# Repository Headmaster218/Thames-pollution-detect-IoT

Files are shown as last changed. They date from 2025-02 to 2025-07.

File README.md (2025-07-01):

# Intelligent Waterborne Fecal Contamination Monitoring System

## AquaSense

This project presents a **low-cost, deployable, AI-integrated platform** for monitoring fecal contamination in natural waters. By using **inorganic water quality parameters** (e.g., DO, PH, turbidity, conductivity) as surrogate inputs, the system predicts **E. coli concentration** and collects physical water samples for future validation. It integrates **real-time sensing, wireless transmission, machine learning inference, data visualization, and automated water sampling**, forming a complete perception–prediction–collection loop.

## 🎥 Video preview

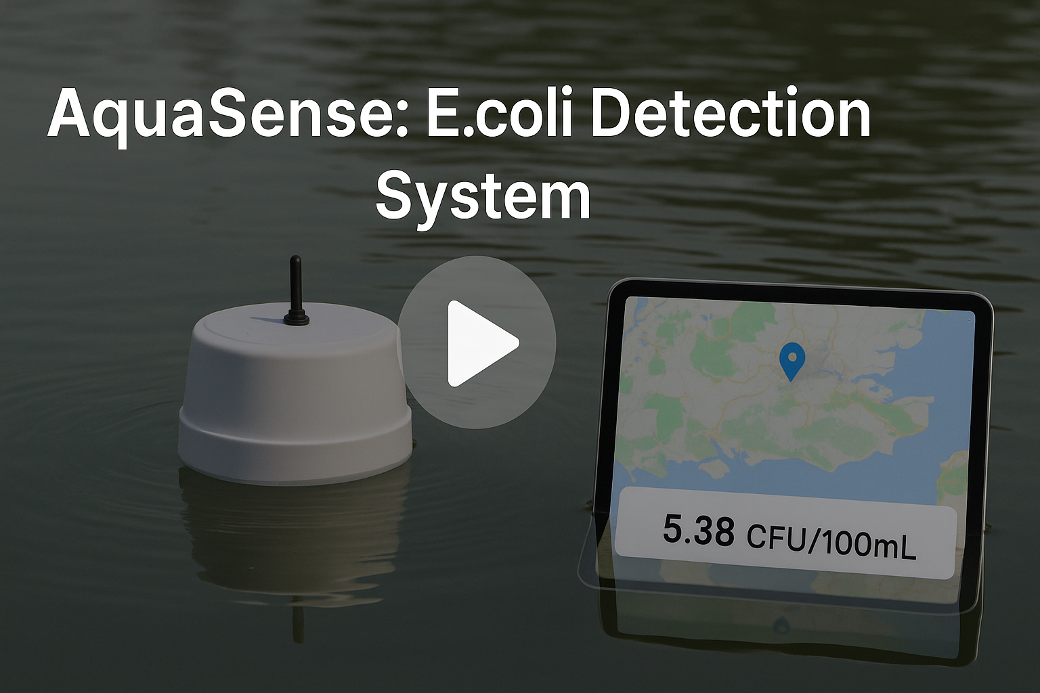
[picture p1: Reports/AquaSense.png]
Press Here~


---

## 📦 Project Summary

- **Title:** Integrated AI-driven Monitoring and Sampling System for Fecal Contamination in Urban Waters  
- **Core Idea:** Replace expensive, time-delayed E. coli testing methods with an inorganic-indicator-based prediction model
- **Application Scenario:** Urban rivers (e.g., Thames), lakes, and distributed low-resource field sites  

---

## 🧠 System Architecture

```
       +------------------+      LoRa        +-------------------+
       | Floating Buoy    |----------------->| LoRa Gateway      |
       | (Sensors + MCU)  |                  | (MQTT Broker)     |
       +--------+---------+                  +-------------------+
                |                                        |
                | LoRa                                   v MQTT
      +---------v---------+                       +---------------+
      | Autonomous Sampler|                       | Cloud Server  |
      | (RTC + Pump +     |<--------------------->| Data Storage  |
      |  Bottle Rotation) |                       +------+--------+
      +-------------------+                              |
                                                         v
                                 +-------------------------------+
                                 |   Web Dashboard & Mobile App  |
                                 |   (Real-time + Historical)    |
                                 +-------------------------------+
```
---

## 🧩 System Modules

### 1. 🧪 Sensor Unit (Floating Buoy)
- Turbidity, Dissolved Oxygen, PH, conductivity sensors
- Arduino-based circuit with solar power
- Periodic sampling + LoRa transmission

### 2. 🔄 Autonomous Sampling Unit 
- Peristaltic pump + rotating vial mechanism
- RTC-controlled periodic water collection
- Time-synced with sensor data via LoRa

### 3. 🌐 Server & Visualization
- LoRa gateway + MQTT + Python backend
- Database (SQLite)
- Web frontend with charts and map
- Mobile app with charts and map

### 4. 🧠 Machine Learning Module
- Trained neural network (FCN) on public water data (~23GB → 1MB preprocessed)
- Predicts log-scaled E. coli concentration
- RMSE ≈ 0.83 on test set
- Optional model variants: XGBoost, RF for comparison

---

## ⚙️ Deployment Features

- Fully solar-powered, suitable for field deployment
- Wireless transmission via LoRa (long range, low power)
- Real-time + historical data access
- Expandable to swarm systems or RL-based control

---

## 🚀 Key Contributions

- ✅ First attempt to estimate fecal contamination using only inorganic indicators  
- ✅ End-to-end system: sensing, prediction, visualization, sampling  
- ✅ Open-source, low-cost, and designed for global scalability  
- ✅ Modular and extensible: supports AI upgrades, edge deployment, or swarm coordination  

---

## 📌 Future Directions

- Integrate control strategies (e.g., RL-based adaptive sampling)  
- Train with real E. coli lab data using automated sampler  
- Edge deployment of ML model on MCU (TinyML)  
- Multi-node deployment and anomaly correlation  

---

## 📁 Folder Structure

```
Root/
├── 3D_Models/        # CAD models
├── Arduino_Code/     # Embedded firmware
├── Backend_code/     # Backend services, APIs
├── MLcode_Tommy_try/ # Experimental ML models by "Tommy"
├── ML_Main/          # Main ML pipeline: data, preprocess, training, model
├── Reports/          # Project documentation, research papers, final reports
└── Visualization/    # Frontend interfaces for data visualization and monitoring
    ├── APP/          # Mobile app interface "BlueGuardian"
    └── Web/          # Web dashboard 
```
---
## Author
Zhuohang Wu @
zhuohang2024@163.com

---

## 📬 Contact & Acknowledgements

For technical inquiries, collaboration requests, or feedback, feel free to contact:

**📌 Project Lead:**  
Zhuohang Wu (John) – zhuohang2024@163.com

**👥 Team Members:**  
Chenghao Xin, Xueyin Fan

**🧑‍🏫 Supervisors:**  
- Dr. Akin Delibasi – Department of Computer Science, UCL  
- Dr. Valerio Modugno – Department of Computer Science, UCL  
- Dr. Izzy Bishop – Department of Genetics, Evolution & Environment, UCL

---

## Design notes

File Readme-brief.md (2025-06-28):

# Project Summary: Low-Cost AI-Based Water Quality Monitoring System

This project aims to develop a **low-cost, deployable monitoring system** for detecting **fecal contamination** (specifically *E. coli*) in surface waters by using **inorganic water quality parameters** (e.g., turbidity, DO, Temperature, pH, conductivity) as surrogate indicators, combined with a machine learning model.

We have built a **fully integrated system** including real-time data collection, wireless transmission, AI-based prediction, web/mobile visualization, and a hardware module for **automatic water sampling**.

---

## ✅ Key Features

- **Inorganic surrogate-based prediction** of E. coli levels using a neural network  
- **Low-power floating buoy** with Arduino + sensors + solar power + LoRa transmission  
- **Web and mobile dashboard** showing real-time and historical data  
- **Autonomous sampling unit** that collects water samples at scheduled intervals for future lab testing  
- **Preliminary model** trained on public data (log-scale RMSE ≈ 0.83)

## 🎥 Video preview

Press Here~

---

## 📦 System Components

1. **Hardware:**  
   - turbidity, DO, Temperature, pH, conductivity sensors  
   - Arduino + LoRa + solar-powered buoy  
   - Peristaltic pump + rotating bottle module (sampler)

2. **Software:**  
   - Arduino + LoRa + MQTT server + database  
   - Web dashboard & mobile app with map and data queries

3. **AI Module:**  
   - Fully connected neural network  
   - Training data from UK water quality datasets  
   - Predicts log-transformed E. coli concentration

---

## 🎯 Project Goals

- Demonstrate feasibility of **non-biological real-time E. coli estimation**  
- Build a **complete monitoring + sampling platform** for environmental deployment  
- Prepare for future lab-based E. coli validation and AI model refinement

---

## 🔄 Current Status

- ✅ Core sensing and data transmission system completed  
- ✅ Dashboard and app functional  
- ✅ AI model trained with promising performance  
- 🛠️ Autonomous sampler hardware under construction (expected to complete soon)

---

## Author
Zhuohang Wu 
zhuohang2024@163.com

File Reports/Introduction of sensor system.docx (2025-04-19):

# Introduction of the sensor system

# final project

John Wu, MSc Internet of things, Computer science.

By the end of 20th of March 2024, human waste has been pumped into the Greater London area of the River Thames for a staggering 1,914 hours since the start of 2024 – equivalent to 79 days [1]! The human waste in it causes Waterborne Diseases, millions of pounds of financial loss and 116 thousand fish dying [2] in the river annually. However, detecting, tracing and predicting the source, distraction and trend of human waste is still a big problem.

Traditionally, people use organic solutions to detect human waste, such as microbial testing, DNA and RNA analysis [3], stable isotope analysis, etc. However, these solutions require expensive devices and a long duration. Based on these shortages, this project plans to develop a lower-cost and faster solution to detect human waste. This project plans to use multi-inorganic content including dissolved oxygen, ammonia nitrogen, conductivity and turbidity with an AI model to judge whether there is human waste in the water sample, what the concentration is and how long it has been in the water. In this solution, the cost is much lower than organic detection. Furthermore, real-time data will be accessible with the help of an AI model. Moreover, using this kind of sensor system, people can monitor the river for 7x24 hours rather than sample by humans and test in the lab.

However, there are still some potential challenges in this situation. For example, there will be a huge amount of data if the whole sensor system is complete. There will be hundreds of sensors, producing data constantly. How to process the data will be one of the most important challenges. Moreover, how to design a durable system is also important. As we all know, the sensors cannot be perfect all the time. Some of them may be broken or even produce wrong data. In this situation, how to make the system robust will be a main challenge.

In summary,

All in all, although with some challenges, this program is still meaningful to not only the citizens in London but also to the economic system in the whole world. This program is making effort on detect, trace and predict many kinds of human waste in the water system. By broaden this new method to the other rivers on this planet, it can provide us a solution to the pollution and make it a better world.

Reference

1. https://riveractionuk.com/thames-water-raw-sewage-dumped-in-the-river-thames-more-than-1900-hours-in-2024-so-far/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,Thames%20Water%3A%20raw%20sewage%20dumped%20in%20the%20River%20Thames%20more,hours%20in%202024%20so%20far&text=Thames%20Water%20has%20pumped%20human,2024%20–%20equivalent%20to%2079%20days
2. https://anglingtrust.net/2024/05/20/huge-increase-in-fish-kills-linked-to-sewage-pollution/
3. Kildare BJ, Leutenegger CM, McSwain BS, Bambic DG, Rajal VB, Wuertz S. 16S rRNA–based assays for quantitative detection of universal, human–, cow–, and dog–specific fecal Bacteroidales: a Bayesian approach. Water Res. 2007 Aug 1;41(16):3701–15.

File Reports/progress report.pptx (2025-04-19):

## Progress Report

- Tommy XIN
- John WU
- Felix FAN

## Detection Progress

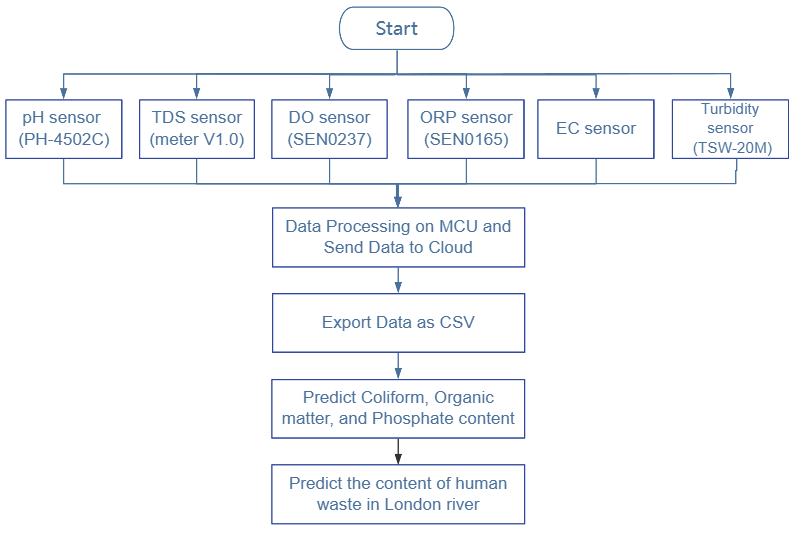
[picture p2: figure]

Can Add More Sensors e.g. Temperature

Need to be Confirmed by More Research

## Detection Progress

Sensors | Detection range | Resolution | Accuracy (25℃)
PH-4502C (pH) | 0-14 pH | 0.01 pH | ±0.1 pH
TSW-20M (Turbidity) | 0-4550 NTU (0%-3.5%) | 4.5 NTU
TDS Meter V1..0 (TDS) | 0-1000 ppm | 1 ppm | ±10% FS
EC sensor (EC) | 0-1000 ppm | 1 ppm | ±10% FS
SEN0237 (DO) | 0~20 mg/L | 0.02 mg/L
SEN0165 (ORP) | -2000 mV-2000 mV | 2 mV | ±10 mV

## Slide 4

Future Plan

Sensors
pH, TDS, Turbidity, EC, DO, and Oxidation-Reduction Potential

Prediction Tasks
- Predict the value of certain index (e.g. coliform)
- Classify whether the water is potable

Data Collecting

Model Training

Build system

Test single system

Deploy multiple systems

Data segmentation

Feature extraction

Training

Test

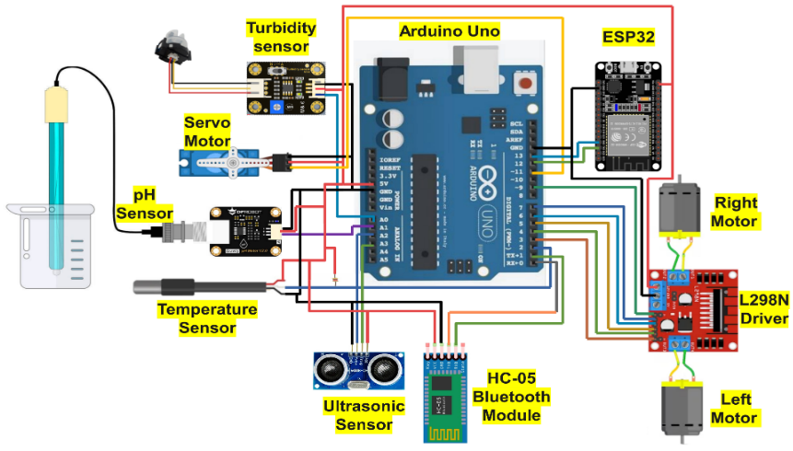
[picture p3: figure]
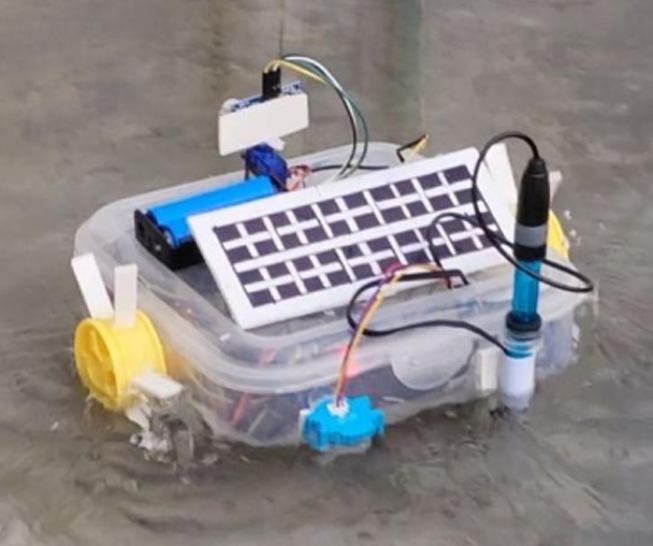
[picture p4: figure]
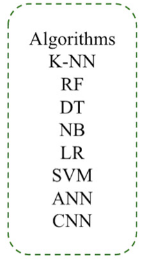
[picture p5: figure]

## Problems

Lack of dataset
- Predict one water pollution index via ML
- Dataset (certain index) is required
Over budget
- DO and ORP probes are expensive
Equipment placement

Component Name | Price (￡)
TDS sensor | 10.39
Turbidity sensor | 14.19
Conductivity sensor | 8.07
pH sensor | 14.84
DO module | 96.41
ORP module | 66.51
Total | 210.41

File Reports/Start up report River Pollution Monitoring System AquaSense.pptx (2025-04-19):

## River Pollution Monitoring System ---- AquaSense

- John WU
- Felix FAN

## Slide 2

0. Content

01

Background

02

Current Methods

03

Novel Solution

Schedule and Challenges

Conclusion

04

05

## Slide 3

1. Background

River Pollution in London
- River test samples:
92% samples -> coliform bacteria;
1% samples -> low dissolved oxygen [2].
- Impact of Coliform on Residents:
Cause intestinal infection, vomiting, etc [3].
- Our Objectives:
Real-time detecting;
Locating contamination

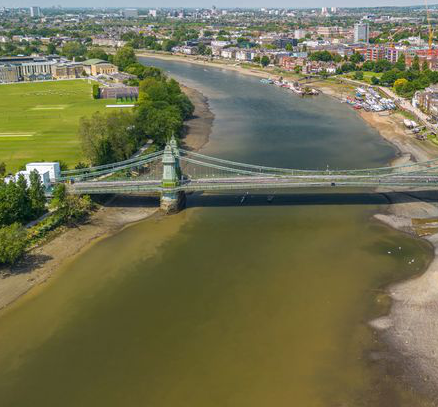
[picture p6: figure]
横跨伦敦西部泰晤士河的哈默史密斯桥的鸟瞰图，连接哈默史密斯和巴恩斯。

Fig. 1. Levels of E.coli were found around Hammersmith Bridge in west London [1]

## 2. Current Methods

Current Methods
- Test in laboratories
- handheld E.coli detection (operation time = 2 hours) [4].
Limitation
- Large-scale manual sampling
- Difficulty updating data
- High economic cost

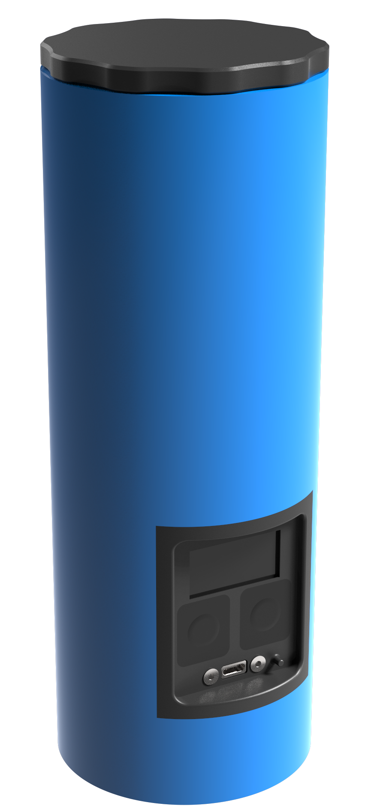
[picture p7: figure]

Fig. 2. E. Coli analyzer [4]

## 3. Novel IoT Solution

Innovations on IoT
- Real-time monitor and analysis
- Multi-device co-work
- Combine ML with pollution monitoring

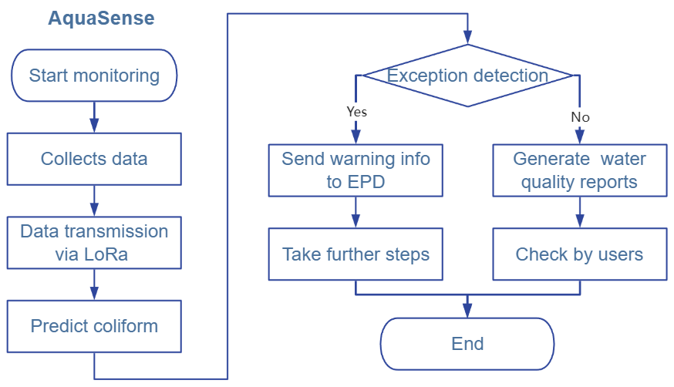
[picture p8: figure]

## 3. Novel Solution

Fig. 4. Block Diagram of sensor

pH sensor

SCC

Analog Signal

Power Supply

Turbidity sensor

SCC

Arduino UNO

TDS sensor

SCC

EC sensor

SCC

DO sensor

SCC

RTC

LORA

LORA transmission

TTL Connection

Fig. 3. Schematic diagram of data transfer

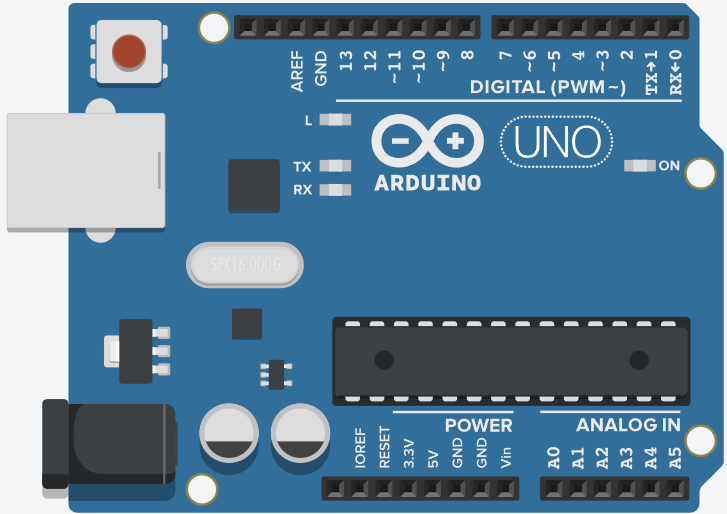
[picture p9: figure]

Arduino with sensors

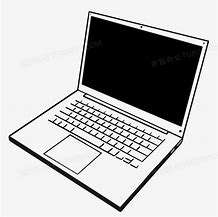
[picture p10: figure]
电脑2d图 的图像结果

Terminal equipment

## 3. Novel Solution

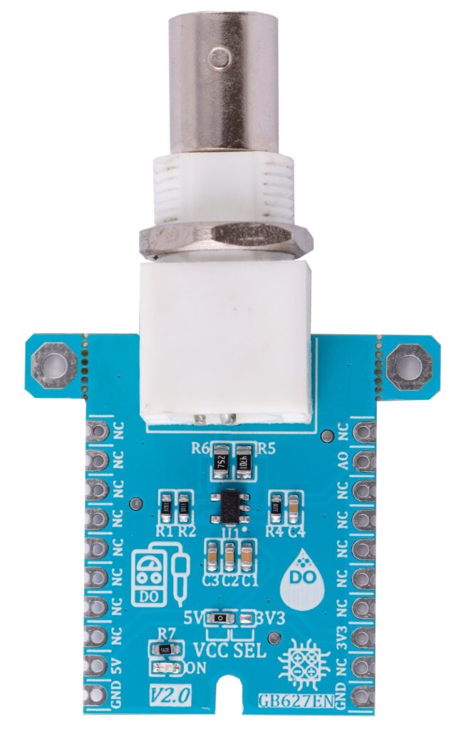
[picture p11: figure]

DO sensor module

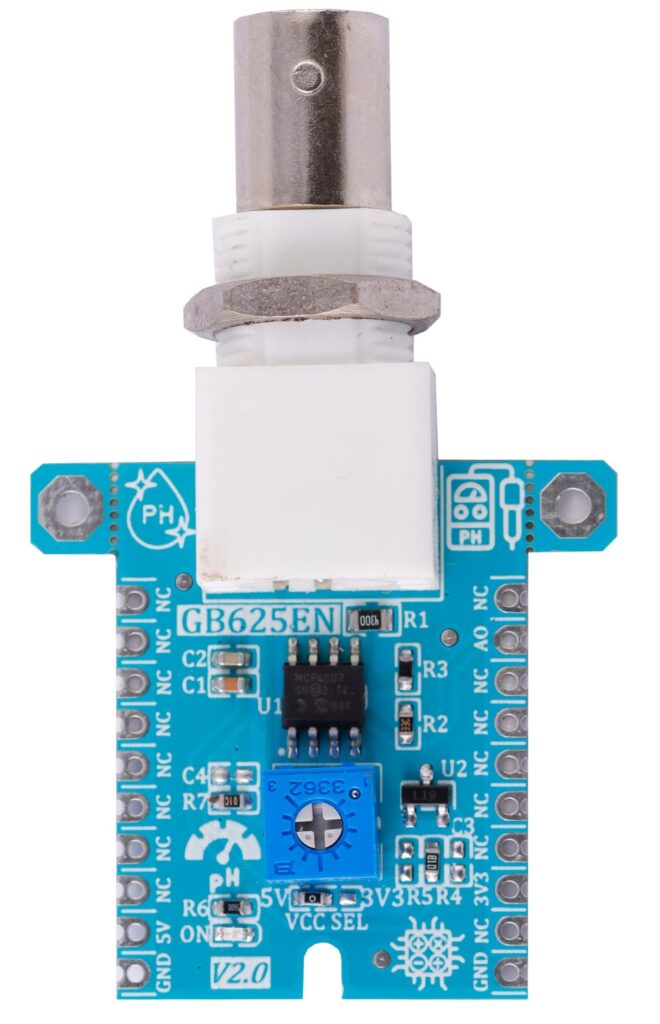
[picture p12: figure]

pH sensor module

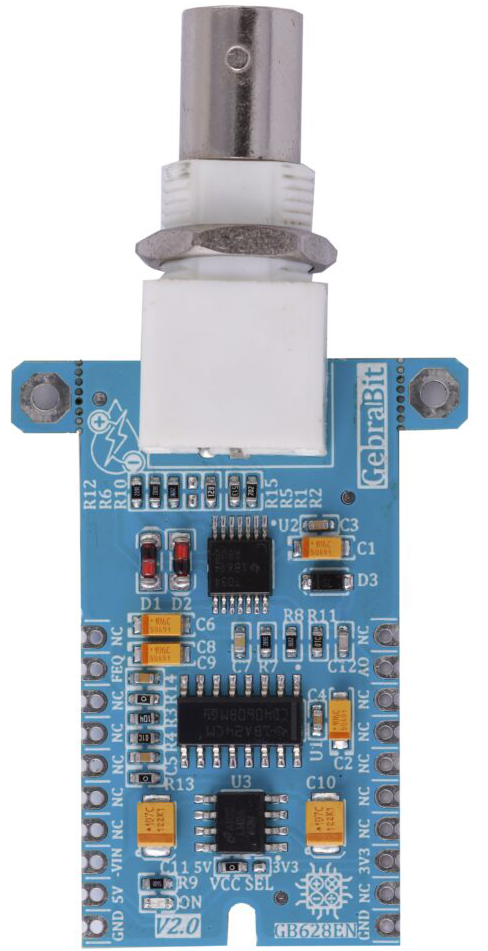
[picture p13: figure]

EC sensor module

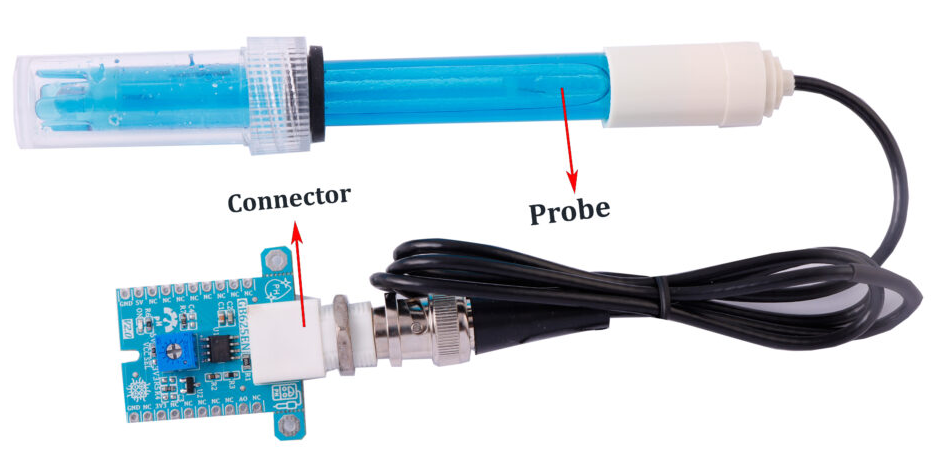
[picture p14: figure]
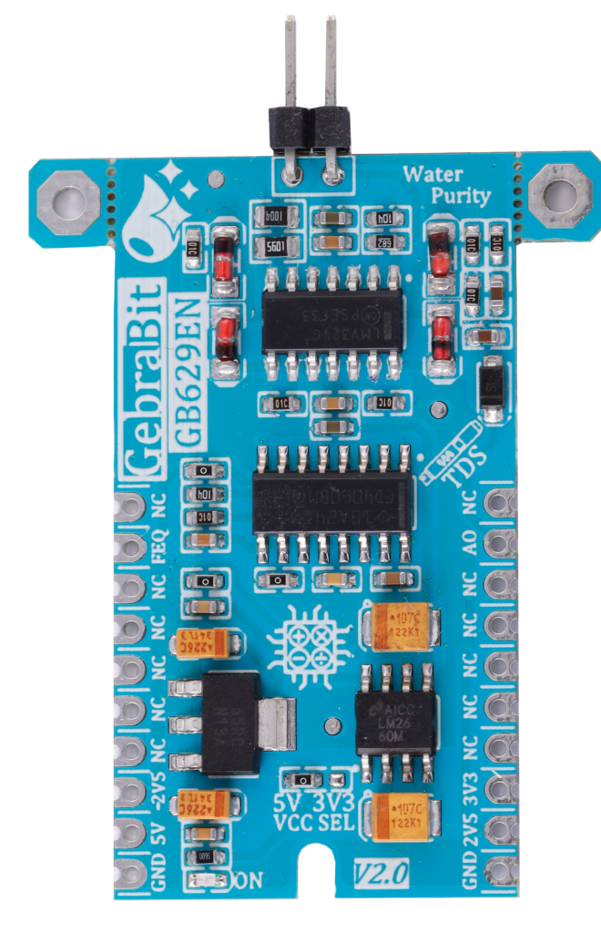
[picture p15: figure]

TDS sensor module

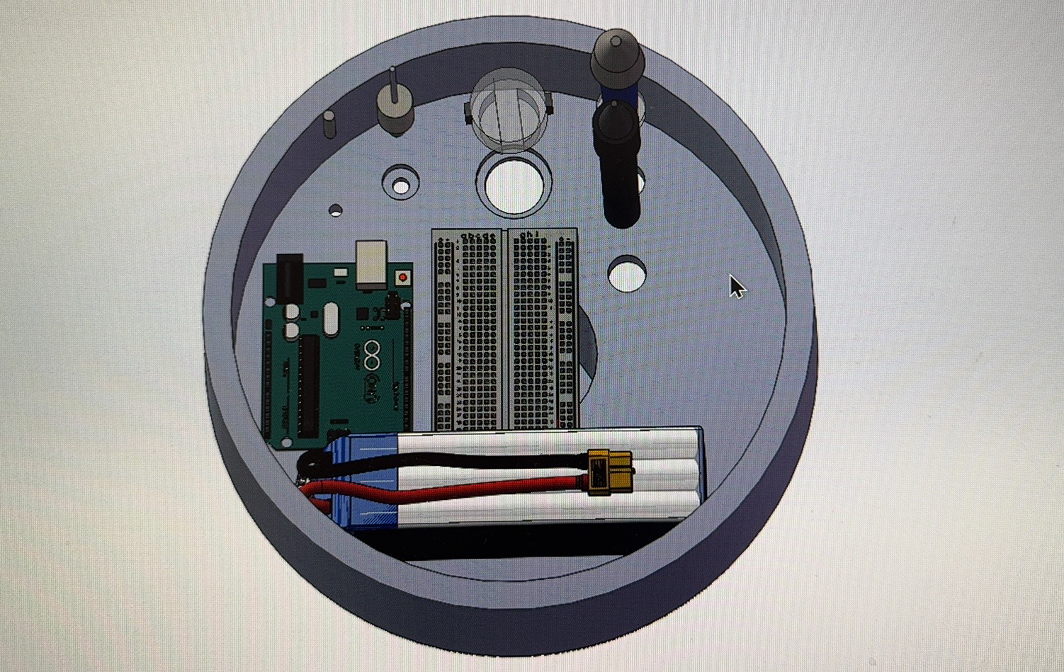
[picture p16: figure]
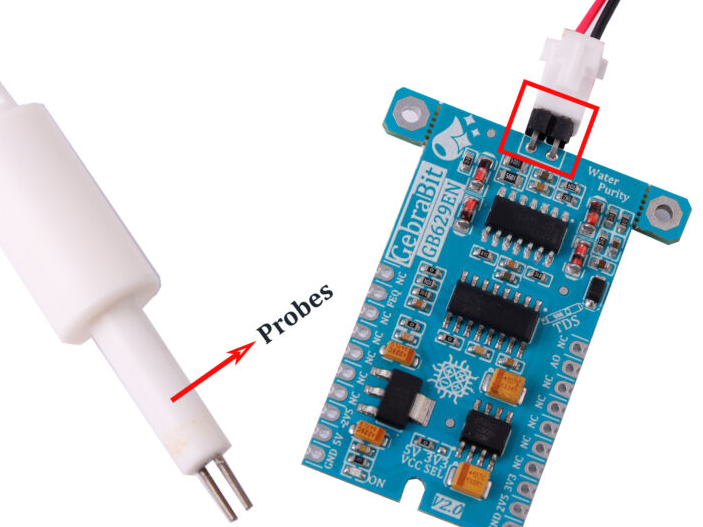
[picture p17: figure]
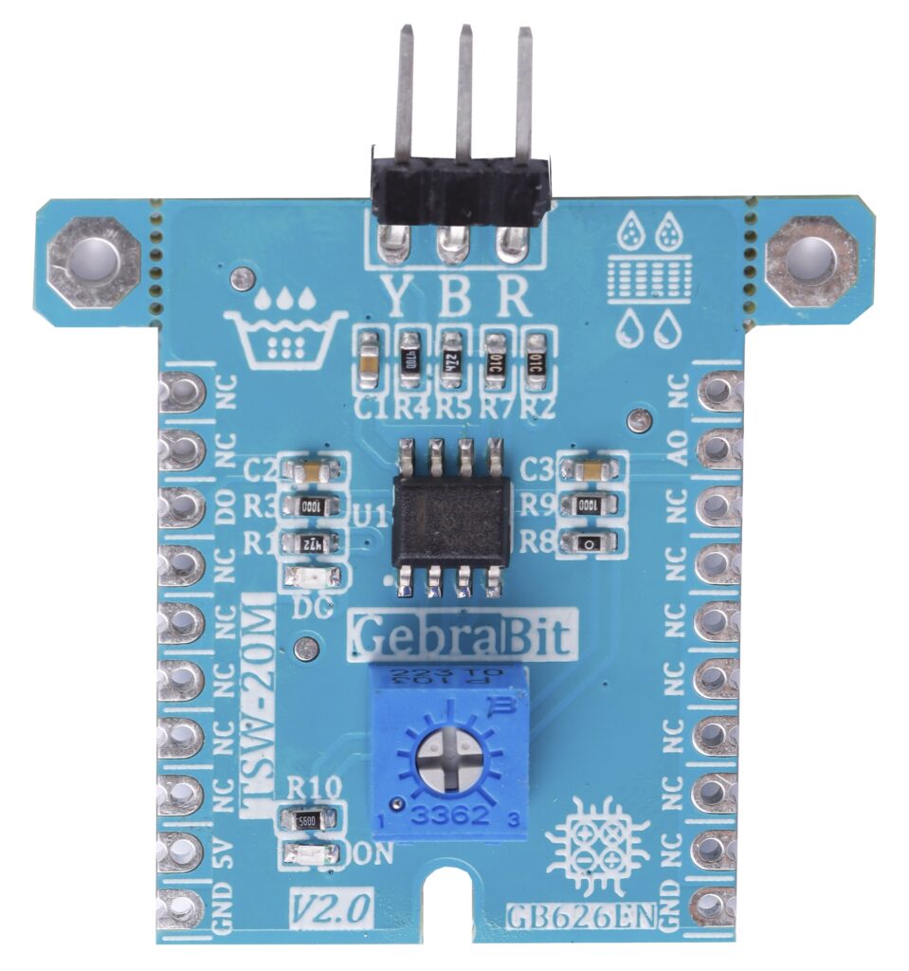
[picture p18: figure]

TSW-20M module

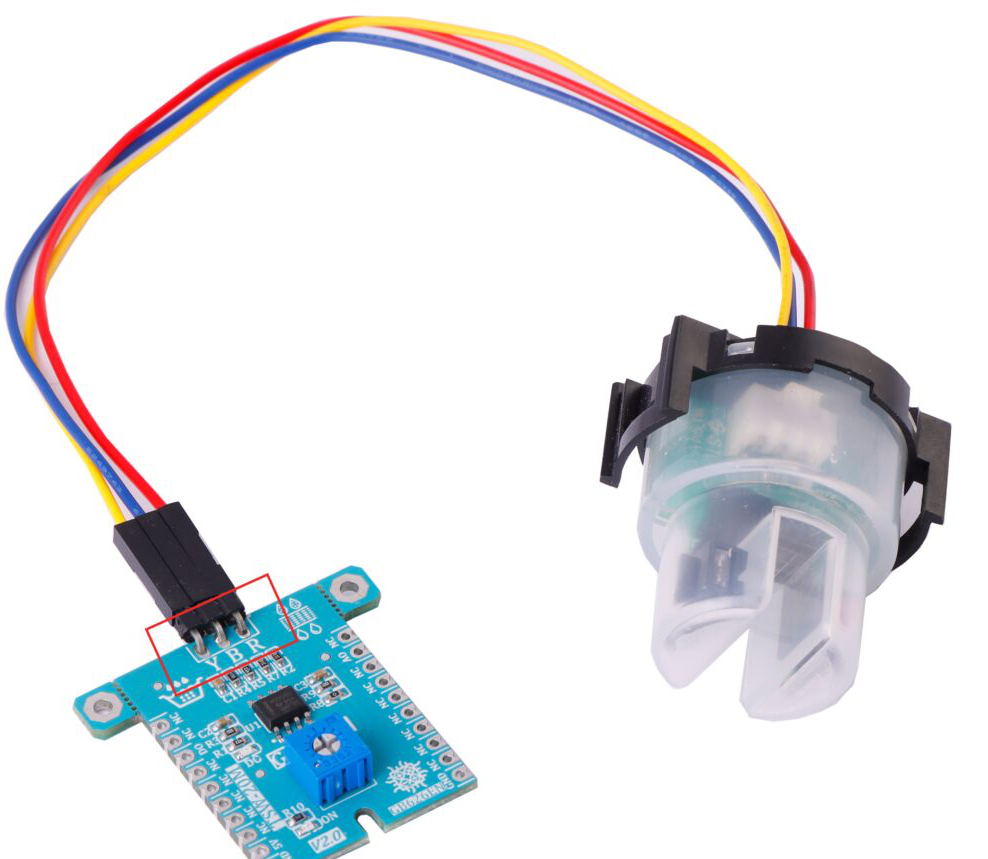
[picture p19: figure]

## 3. Novel Solution

Advantages of applying IoT devices
Utilizing IoT-based system has 3 main advantages .
- Using Arduino platform -> strong expansibility and flexibility,
- Using cheap components -> lower cost,
- Use remote monitoring based on Wi-Fi -> convenient,
- ……

## 4. Management and Challenges

Time Management

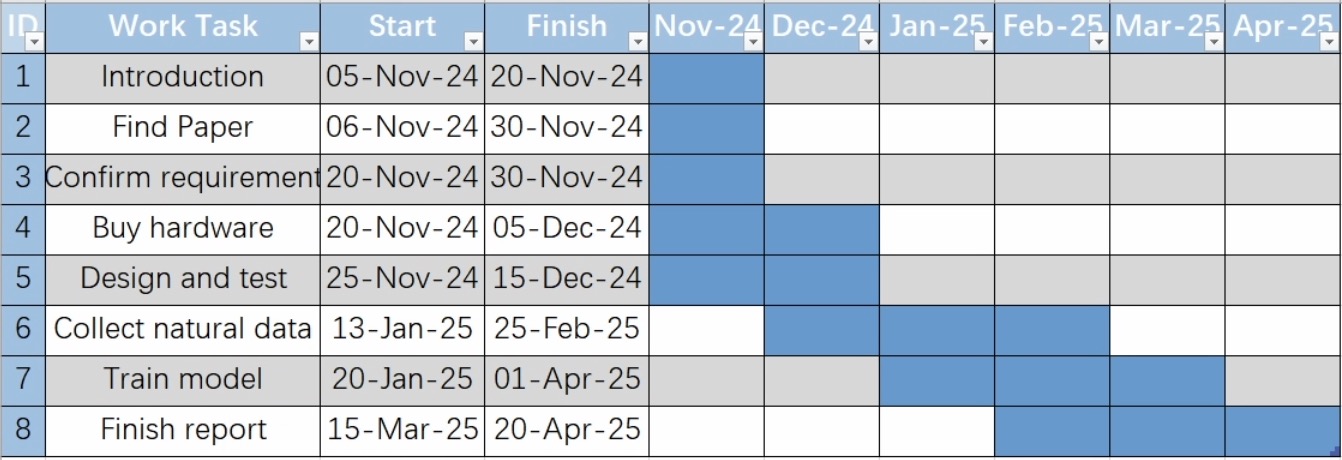
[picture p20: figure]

Fig. 5. Gantt Chart

## 4. Management and Challenges

Type | Price | Quantity
ESP32-S3 Board | In stock | Depend on the number of sampling locations
Bread Board | In stock
Wires | In stock
Battery | ￡6.99 each
Turbidity Module | ￡6.45 each
DO Module | ￡3.08 each
TDS Module | ￡10.39 each
pH Module | ￡14.31 each
EC Module | ￡8.07 each

Materials
- 3D printer
- Server
- MCU
- Several sensors [6]

## 4. Management and Challenges

Possible Challenges | Solutions
Damage to IoT equipment | Provide identification plate Regular inspection
Over budget | Reduce sampling sites
Unstable of device and connection | stable power supply Use large area coverage Wi-Fi

## 5. Conclusion

Advantages
Strong expansibility and low cost

IoT Monitoring System

Innovations
Using IoT devices to study pollution in London's rivers

Challenges
Device stability and budget control

## Thank you!

## Reference

[1] M. Allen, “Findings of high Thames E.coli levels discovered, as new guidance issued to rowers,” River Action UK, Mar. 27, 2024. https://riveractionuk.com/findings-of-high-thames-e-coli-levels-discovered-as-new-guidance-issued-to-rowers/
[2] “Water Quality Results,” Thames21. https://www.thames21.org.uk/water-quality-results/
[3] “‘Alarmingly high’ levels of E.coli in River Thames found days before Oxbridge Boat Race,” Sky News. https://news.sky.com/story/alarmingly-high-levels-of-e-coli-in-river-thames-found-days-before-oxbridge-boat-race-13102682
[4] Super Utilisateur, “Fluidion ALERT One,” Fluidion.com, 2024. https://fluidion.com/products/analyzers/alert-one (accessed Nov. 14, 2024).
[5] J. Fonseca-Campos, I. Reyes-Ramirez, L. Guzman-Vargas, L. Fonseca-Ruiz, J. A. Mendoza-Perez, and P. F. Rodriguez-Espinosa, “Multiparametric System for Measuring Physicochemical Variables Associated to Water Quality Based on the Arduino Platform,” IEEE Access, vol. 10, pp. 69700–69713, 2022, doi: https://doi.org/10.1109/access.2022.3187422.
[6] “Sensors - GebraBit,” GebraBit, Aug. 19, 2024. https://gebrabit.com/en/sensors/.

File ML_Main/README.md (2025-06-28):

# AquaSense · Machine-Learning Module  
*Lightweight AI for Field-Deployable E. coli Estimation*

> **Core idea:** Estimate **E. coli concentration** using only five low-cost physicochemical indicators (O₂, temperature, pH, turbidity, conductivity) with a compact neural network (~18k parameters). The system eliminates the need for 18–24h lab incubation, enabling near-real-time microbial risk assessment in urban water systems.

---

## 1 · Task Definition

- **Input**: 44 proxy features (including statistical and trigonometric derivatives of 5 core indicators)
- **Output**: `ln Coliform` — natural logarithm of coliform counts (CFU per 100 mL)

---

## 2 · Model Architecture

| Layer | Output Dim | Details |
|---|---|---|
| FC-1  | 128 | LeakyReLU(α=0.01) + Dropout(0.25) |
| FC-2  | 64 | LeakyReLU + Dropout(0.25) |
| FC-3  | 32 | LeakyReLU + Dropout(0.25) |
| Output | 1 | Linear activation |

- **Optimizer**: Adam (lr = 1e-4, weight_decay = 1e-4)  
- **Loss Function**: HuberLoss  
- **LR Scheduler**: StepLR (step = 100, γ = 0.9)  
- **Early Stopping**: patience = 50

> ⚙️ ~18k trainable parameters — compatible with Raspberry Pi, ESP-32 and other embedded platforms.

---

## 3 · Performance Comparison

| Method | RMSE ↓ | MAE ↓ | R² ↑ |
|---|---|---|---|
| Turbidity-only LR | 1.98 | 1.62 | 0.12 |
| Linear Regression | 1.95 | 1.54 | 0.14 |
| Random Forest | 1.74 | 1.34 | 0.32 |
| XGBoost | 1.79 | 1.37 | 0.28 |
| MLP-2L | 1.88 | 1.41 | 0.20 |
| **CNN-DropHuber (Ours)** | **0.82** | **0.72** | **0.37** |

<details>
<summary>Click to view Feature Importance (XGBoost)</summary>

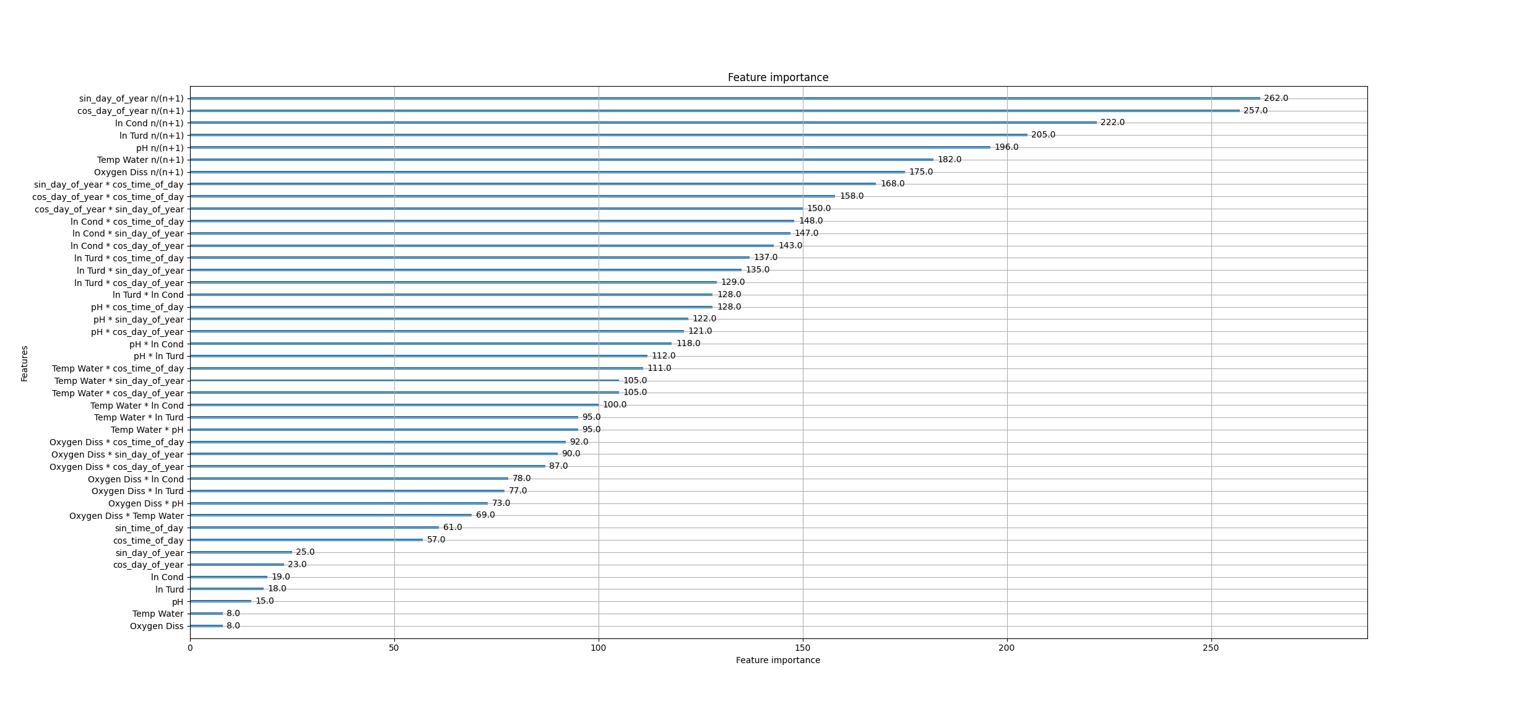
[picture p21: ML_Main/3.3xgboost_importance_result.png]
feat


</details>

---

## 4 · Output Files

| Path | Description |
|---|---|
| `model_best_val_loss.pth` | Best model weights (lowest val RMSE) |
| `scaler.pkl` | StandardScaler object (used during training) |
| `baseline_results.csv` | RMSE / MAE / R² of all baseline models |
| `3.1loss+R2_whole.png` | Training & validation loss curve |
| `pred_true_scatter.png` | Prediction vs. Ground Truth (scatter) |

---

## 5 · Contact

Project Lead: **John Wu**

Feel free to open an issue or submit a pull request on GitHub.

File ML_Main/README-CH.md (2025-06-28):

# AquaSense · Machine-Learning Module  
*Lightweight AI for Field-Deployable E. coli Estimation*

> **Core idea:** 以 **五项低成本物理化学指标**（O₂、温度、pH、浊度、导电率）为特征，用 18 k 参数的小型神经网络在现场近实时估计 **E. coli** 含量，免去 18-24 h 培养等待 —— 为快速水质预警提供可落地方案。

---

## 1 · 任务定义
- **输入**：44 维 proxy 特征（原始 5 项＋统计 / trigonometric 派生特征），已做 log 或标准化转换  
- **输出**：`ln Coliform` —— 对 E. coli CFU · 100 mL⁻¹ 的自然对数  

---

## 2 · 模型结构

| 层级 | 输出维度 | 细节 |
|---|---|---|
| FC-1 | 128 | LeakyReLU(α=0.01) + Dropout(0.25) |
| FC-2 | 64 | LeakyReLU + Dropout(0.25) |
| FC-3 | 32 | LeakyReLU + Dropout(0.25) |
| Output | 1 | 线性激活 |

*优化器* Adam (lr 1e-4, weight_decay 1e-4) | *损失函数* HuberLoss  
*LR 调度* StepLR(step = 100, γ = 0.9) | *早停* patience = 50

> **参数总量** ≈ 18 k —— 适合 Raspberry Pi / ESP-32 边缘设备部署。

---

## 3 · 性能对比

| 方法 | RMSE ↓ | MAE ↓ | R² ↑ |
| --- | --- | --- | --- |
| Turbidity-only LR | 1.98 | 1.62 | 0.12 |
| Linear Regression | 1.95 | 1.54 | 0.14 |
| Random Forest | 1.74 | 1.34 | 0.32 |
| XGBoost | 1.79 | 1.37 | 0.28 |
| MLP-2L | 1.88 | 1.41 | 0.20 |
| **CNN-DropHuber (Ours)** | **0.82** | **0.72** | **0.37** |

<details>
<summary>点击查看 Feature Importance (XGBoost)</summary>

feat

</details>

---

## 4 · 输出文件

| 路径 | 描述 |
| --- | --- |
| `model_best_val_loss.pth` | 最佳权重 (val RMSE 最低) |
| `scaler.pkl` | StandardScaler 对象 (训练阶段保存) |
| `baseline_results.csv` | 所有对比模型 RMSE / MAE / R² |
| `3.1loss+R2_whole.png` | 训练-验证损失曲线 |
| `pred_true_scatter.png` | 预测 vs 真值散点图 |

---

## 5 · 联系

项目负责人：**John Wu**

Issue / PR 欢迎直接在 GitHub 提交。

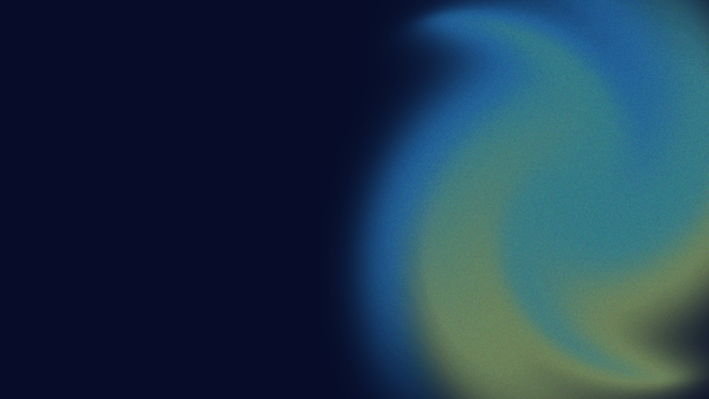
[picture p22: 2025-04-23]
Visualization/Web/flask4.20/templates/BG.png

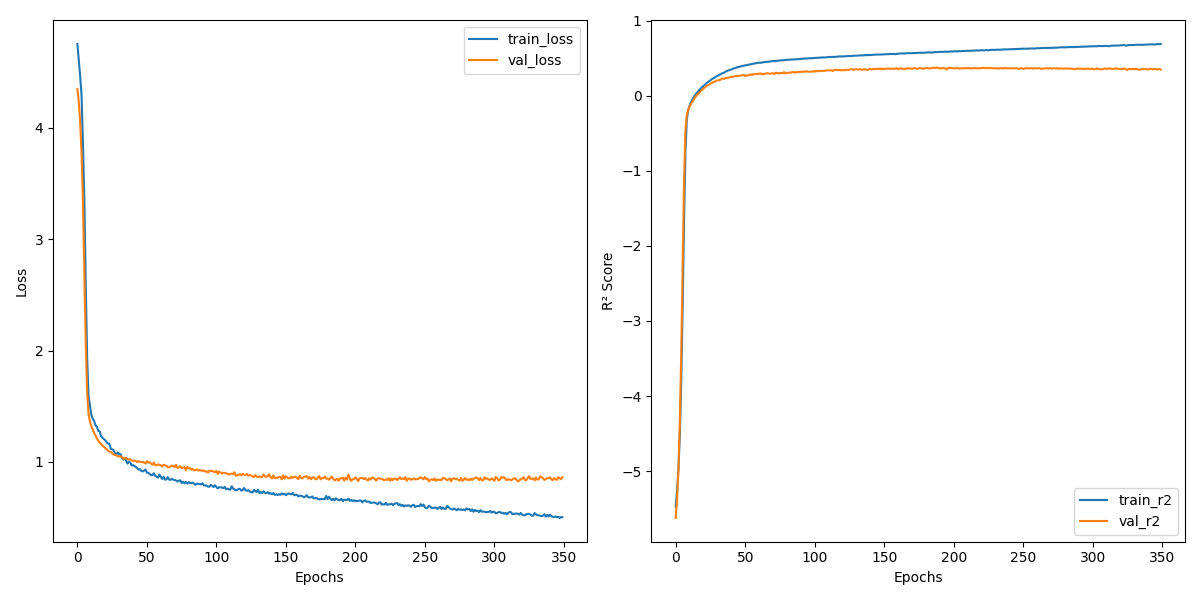
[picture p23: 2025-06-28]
ML_Main/3.1loss+R2_whole.png

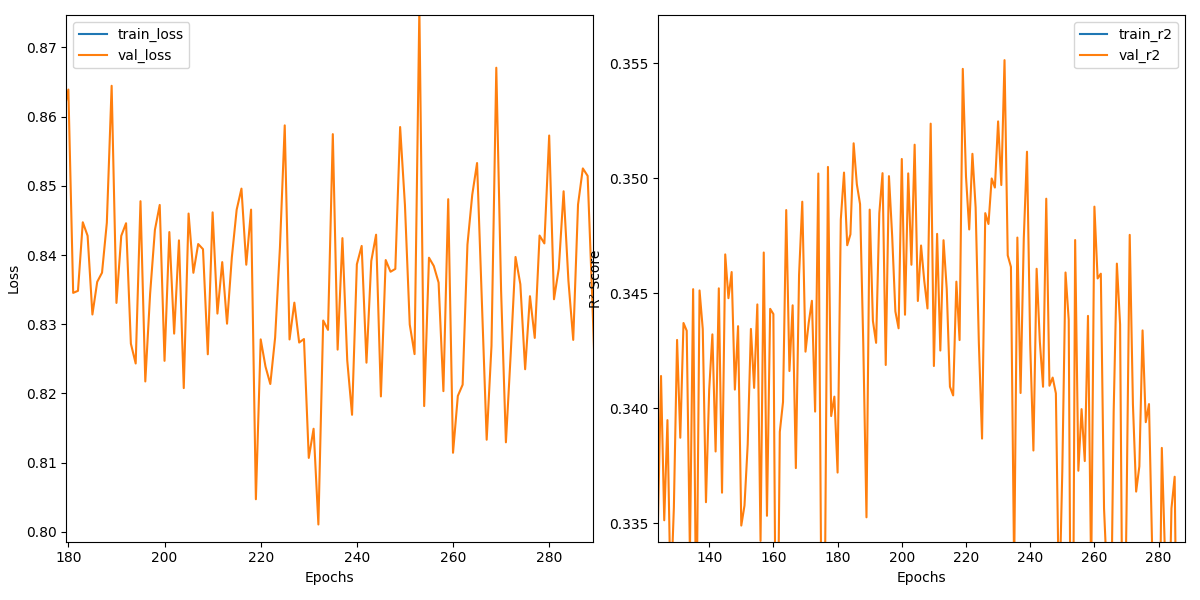
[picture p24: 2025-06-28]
ML_Main/3.1loss+R2(2).png

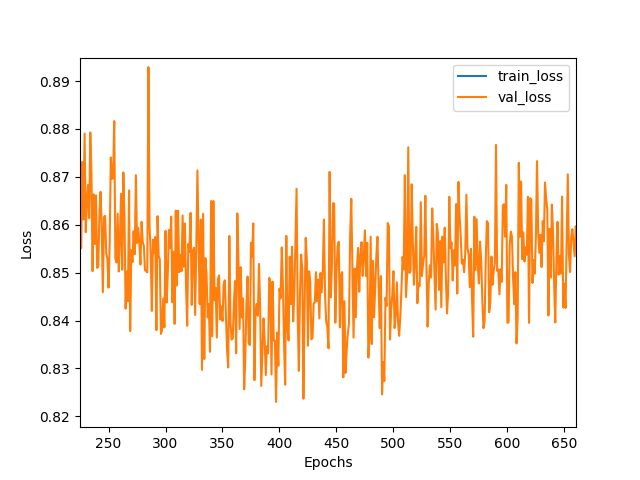
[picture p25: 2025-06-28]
ML_Main/3.1min_loss.png

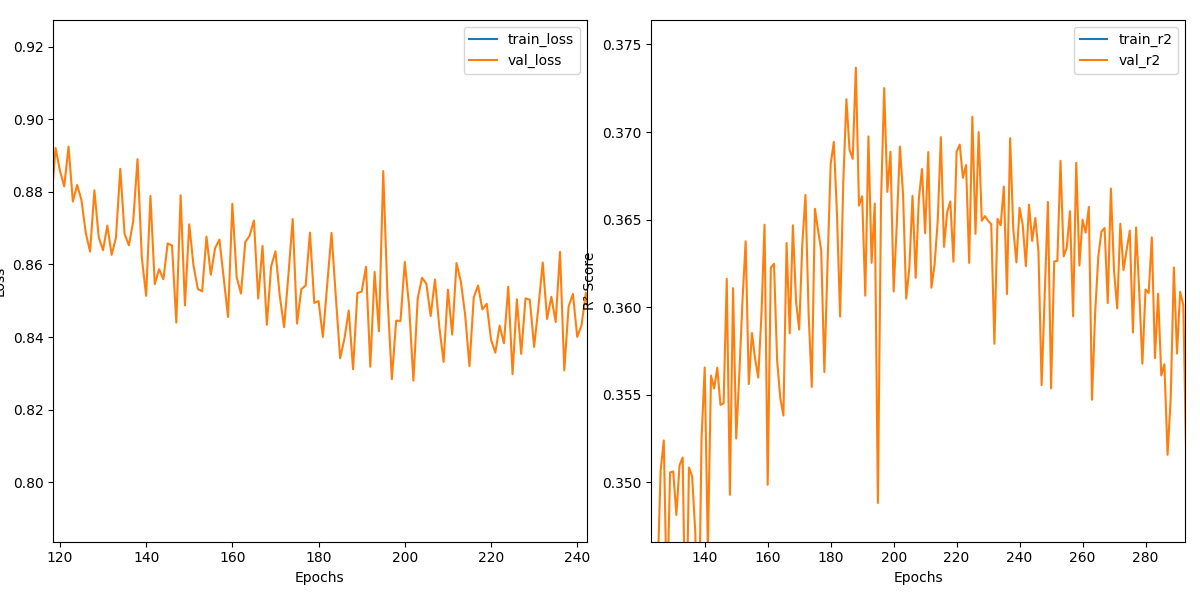
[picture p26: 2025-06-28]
ML_Main/3.1loss+R2.png

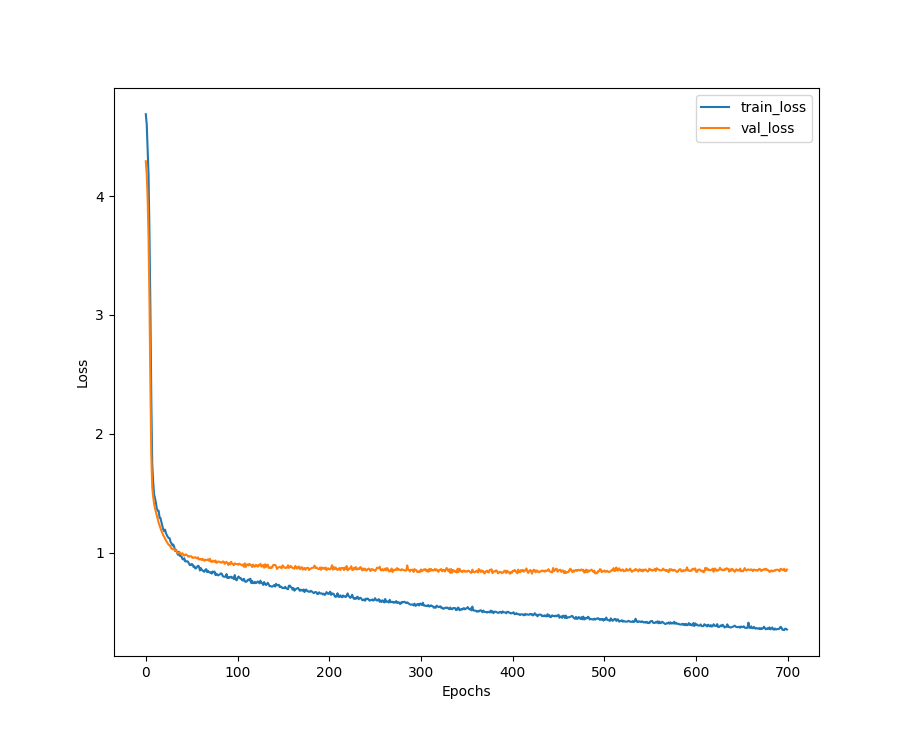
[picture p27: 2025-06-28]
ML_Main/3.1loss.png

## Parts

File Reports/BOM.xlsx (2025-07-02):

Part | Component | Price for each (￡) | Amount | Link
Floating Station | Turbidity sensor | 14.19 | 1 | https://www.amazon.co.uk/gp/product/B07SLRRX38/ref=ewc_pr_img_6?smid=A68YOTXQQLJUV&psc=1
 | Conductivity sensor | 8.07 | 1 | https://www.amazon.co.uk/gp/product/B08S3YN64X/ref=ewc_pr_img_5?smid=AYI7V3Q1N9YLM&psc=1
 | Temperature sensor | 8.39 | 1 | Youmile MAX31865 PT100/PT1000 RTD Temperature Thermocouple Sensor Amplifier Board 3.3/5V Temperature Detector Module for Arduino with -50 to 200℃ 0.5m/1.6ft 3 Wires PT100 RTD Sensor Probe : Amazon.co.uk: Business, Industry & Science (https://www.amazon.co.uk/Youmile-MAX31865-Temperature-Thermocouple-Amplifier/dp/B091FH3L9P?nsdOptOutParam=true)
 | pH sensor | 14.84 | 1 | https://www.amazon.co.uk/gp/product/B0DLKDFSMF/ref=ewc_pr_img_4?smid=A3LX5U4CP7R85Q&psc=1
 | DO module | 125.39 | 1 | https://www.dfrobot.com/product-1628.html
 | Boost circuit link | 8.99 | 1 | https://www.amazon.co.uk/eMagTech-Booster-Converter-Adjustable-Regulator/dp/B0DM7HLHSD
 | 3.7V -> 5V boost | 7.99 | 1 | https://www.amazon.co.uk/Lithium-Battery-Charging-Protection-Functions/dp/B08DQXPNR1
 | 3.7V Li battery | 11.59 | 2 | https://www.amazon.co.uk/EEMB-Rechargeable-Replacement-103395-Connector/dp/B08215B4KK?xpid=d5yoZTvKDxVpq
 | arduino uno wifi rev2 | 49.8 | 1 | https://www.amazon.co.uk/Arduino-UNO-WiFi-Rev-2/dp/B07MK598QV?sp_csd=d2lkZ2V0TmFtZT1zcF9hdGY
 | Solar panel | 10.89 | 1 | https://www.amazon.co.uk/Electronic-Component-Solar-Security-Camera/dp/B0DP4HRB7H?rnid=118657031
 | Total | 260.14
Sampler | fishing rod | 19.9 | 1 | https://www.amazon.co.uk/Starvortex-Fishing-45cm-176cm-Telescopic-Beginner/dp/B0DZHG365K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
 | Pump | 9.88 | 1 | Gikfun 12V DC Dosing Pump Peristaltic Dosing Head with Connector For Arduino Aquarium Lab Analytic Diy AE1207U : Amazon.co.uk: Pet Supplies (https://www.amazon.co.uk/Gikfun-Peristaltic-Connector-Aquarium-Analytic/dp/B01IUVHB8E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) | Gikfun 12V DC Dosing Pump Peristaltic Dosing Head with Connector For Arduino Aquarium Lab Analytic Diy AE1207U : Amazon.co.uk: Pet Supplies (https://www.amazon.co.uk/Gikfun-Peristaltic-Connector-Aquarium-Analytic/dp/B01IUVHB8E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)
 | Tube | 8.59 | 1 | Silicone Tube 2mm ID X 4mm OD, 5 Meters(16.4FT), LAVMHAB Food Grade Hose Flexible Silicone Tubing Clear Water Air Hose Pipes for Pump Transfer : Amazon.co.uk: Business, Industry & Science (https://www.amazon.co.uk/Silicone-Meters-LAVMHAB-Flexible-Transfer/dp/B0BGQHFZ94?th=1) | Silicone Tube 2mm ID X 4mm OD, 5 Meters(16.4FT), LAVMHAB Food Grade Hose Flexible Silicone Tubing Clear Water Air Hose Pipes for Pump Transfer : Amazon.co.uk: Business, Industry & Science (https://www.amazon.co.uk/Silicone-Meters-LAVMHAB-Flexible-Transfer/dp/B0BGQHFZ94?th=1)
 | Motor, 30RPM | 19.29 | 1 | sourcing map 2 Pcs DC 12V 2 RPM Reversible Worm Geared Motor Reducer Motor 6mm D Shape Shaft High Torque Gear Box Reduction Electric Motor for Sweepers, Printers, Ovens : Amazon.co.uk: Business, Industry & Science (https://www.amazon.co.uk/sourcing-map-Reversible-Reduction-Electric/dp/B0DPQPPND7?th=1) | sourcing map 2 Pcs DC 12V 2 RPM Reversible Worm Geared Motor Reducer Motor 6mm D Shape Shaft High Torque Gear Box Reduction Electric Motor for Sweepers, Printers, Ovens : Amazon.co.uk: Business, Industry & Science (https://www.amazon.co.uk/sourcing-map-Reversible-Reduction-Electric/dp/B0DPQPPND7?th=1)
 | 6mm to 6mm | 5.99 | 1 | sourcing map 6pcs 6mm to 6mm Brass Shaft Coupling Joint Connector with Screws Flexible Motor Shaft Coupler for RC Model Car Airplane Motor Wheels Tires Shaft : Amazon.co.uk: DIY & Tools (https://www.amazon.co.uk/sourcing-map-Coupling-Connector-Flexible/dp/B0D424GGW1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) | sourcing map 6pcs 6mm to 6mm Brass Shaft Coupling Joint Connector with Screws Flexible Motor Shaft Coupler for RC Model Car Airplane Motor Wheels Tires Shaft : Amazon.co.uk: DIY & Tools (https://www.amazon.co.uk/sourcing-map-Coupling-Connector-Flexible/dp/B0D424GGW1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)
 | 300 degree servo motor | 15.74 | 1 | PENO Digital Waterproof Servo Double Bearing 300 Degree Rotation Brushless Servo Plastic For 1/8 RC Car For 1/10 RC Model : Amazon.co.uk: Toys & Games (https://www.amazon.co.uk/PENO-Digital-Waterproof-Rotation-Brushless/dp/B0BD2LZVYX) | PENO Digital Waterproof Servo Double Bearing 300 Degree Rotation Brushless Servo Plastic For 1/8 RC Car For 1/10 RC Model : Amazon.co.uk: Toys & Games (https://www.amazon.co.uk/PENO-Digital-Waterproof-Rotation-Brushless/dp/B0BD2LZVYX)
 | Bat and charger | 14.99 | 1 | AMZZN 11.1V 10C 2000mAh Li-ion Battery With SM2P Plug T-Plug Tamiya Plug Conversion Line And USB Charging Cable Suitable For Airsoft Gel Water Bead Blaster Replacement Battery: Amazon.co.uk: Toys & Games (https://www.amazon.co.uk/AMZZN-Conversion-Charging-Suitable-Replacement/dp/B0D62MF4MY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) | AMZZN 11.1V 10C 2000mAh Li-ion Battery With SM2P Plug T-Plug Tamiya Plug Conversion Line And USB Charging Cable Suitable For Airsoft Gel Water Bead Blaster Replacement Battery: Amazon.co.uk: Toys & Games (https://www.amazon.co.uk/AMZZN-Conversion-Charging-Suitable-Replacement/dp/B0D62MF4MY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)
 | Motor Driver | 7.99 | 1 | DUBEUYEW L298N Motor Drive Controller Board Module Dual H Bridge DC Stepper for Arduino Smart Car Robot MEGA R3 2560 ESP32 ESP826(2pcs) : Amazon.co.uk: Business, Industry & Science (https://www.amazon.co.uk/DUBEUYEW-Controller-Module-Stepper-Arduino/dp/B0B4TRWVR8?hvcampaign=electronics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) | DUBEUYEW L298N Motor Drive Controller Board Module Dual H Bridge DC Stepper for Arduino Smart Car Robot MEGA R3 2560 ESP32 ESP826(2pcs) : Amazon.co.uk: Business, Industry & Science (https://www.amazon.co.uk/DUBEUYEW-Controller-Module-Stepper-Arduino/dp/B0B4TRWVR8?hvcampaign=electronics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)
 | 12v-5v buck | 5.99 | 1 | 2Pcs 24V / 12V to 5V 5A Power Buck Converter DC-DC Power Down Module 12V to 5V Converter Efficient Power Conversion Buck Converter Wide Compatibility 12V to 5V Buck Converter Module : Amazon.co.uk: Computers & Accessories (https://www.amazon.co.uk/Converter-Module-Efficient-Conversion-Compatibility/dp/B0DNJ5BFS2?s=computers) | 2Pcs 24V / 12V to 5V 5A Power Buck Converter DC-DC Power Down Module 12V to 5V Converter Efficient Power Conversion Buck Converter Wide Compatibility 12V to 5V Buck Converter Module : Amazon.co.uk: Computers & Accessories (https://www.amazon.co.uk/Converter-Module-Efficient-Conversion-Compatibility/dp/B0DNJ5BFS2?s=computers)
 | Total | 108.36

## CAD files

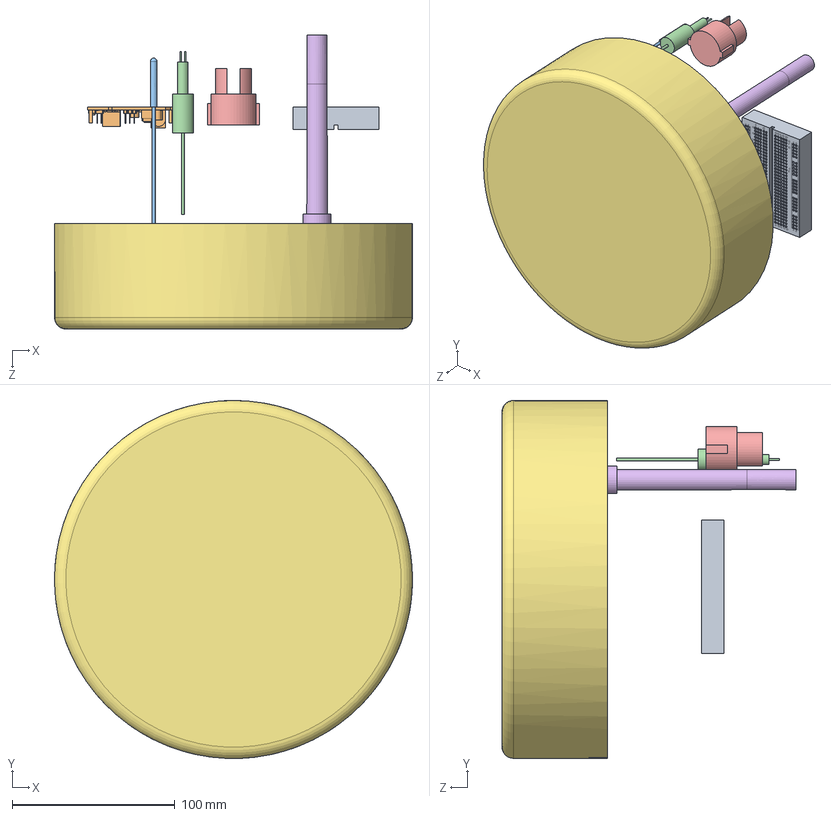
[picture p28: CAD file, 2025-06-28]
3D_Models/Assem1.SLDASM
220.0 x 220.0 x 180.7 mm
top Cover
S Dissolved oxygen
S Turdibity Sensor
S Conductivity Sensor
S Temperature Sensor
Arduino
matrix

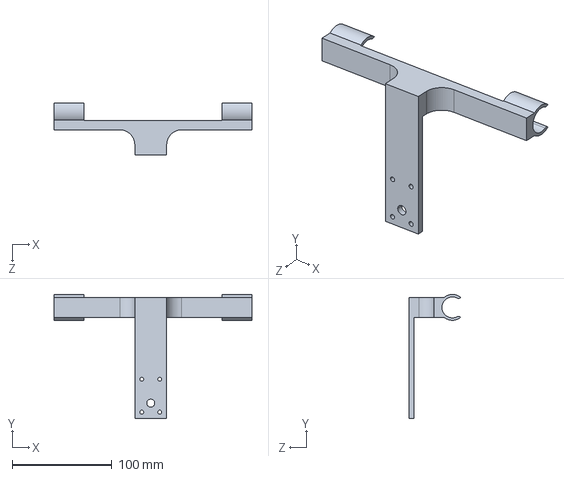
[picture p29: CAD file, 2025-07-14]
Auto_sampler/hardwares/Motor holder.STEP
198.5 x 124.5 x 51.7 mm

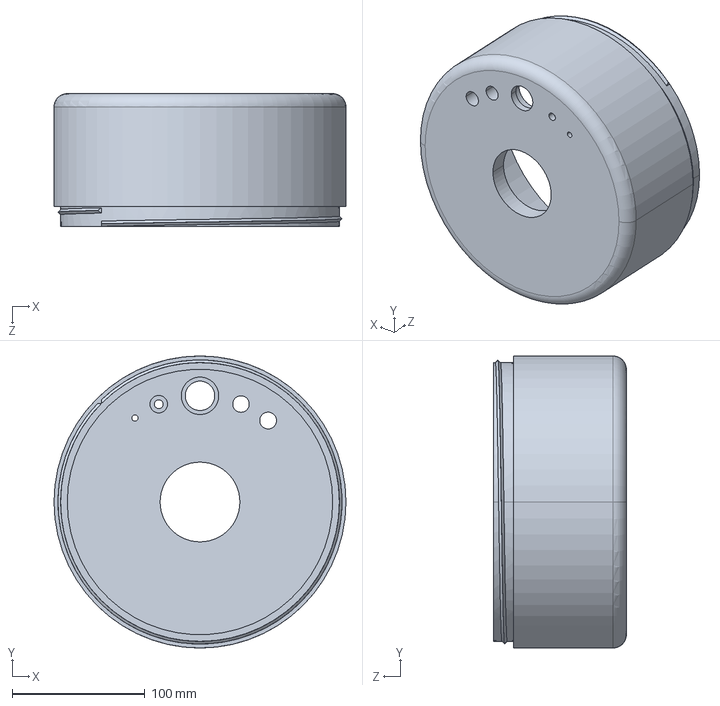
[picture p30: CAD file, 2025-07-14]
3D_Models/out Cover Mid.STEP
220.0 x 220.0 x 100.0 mm

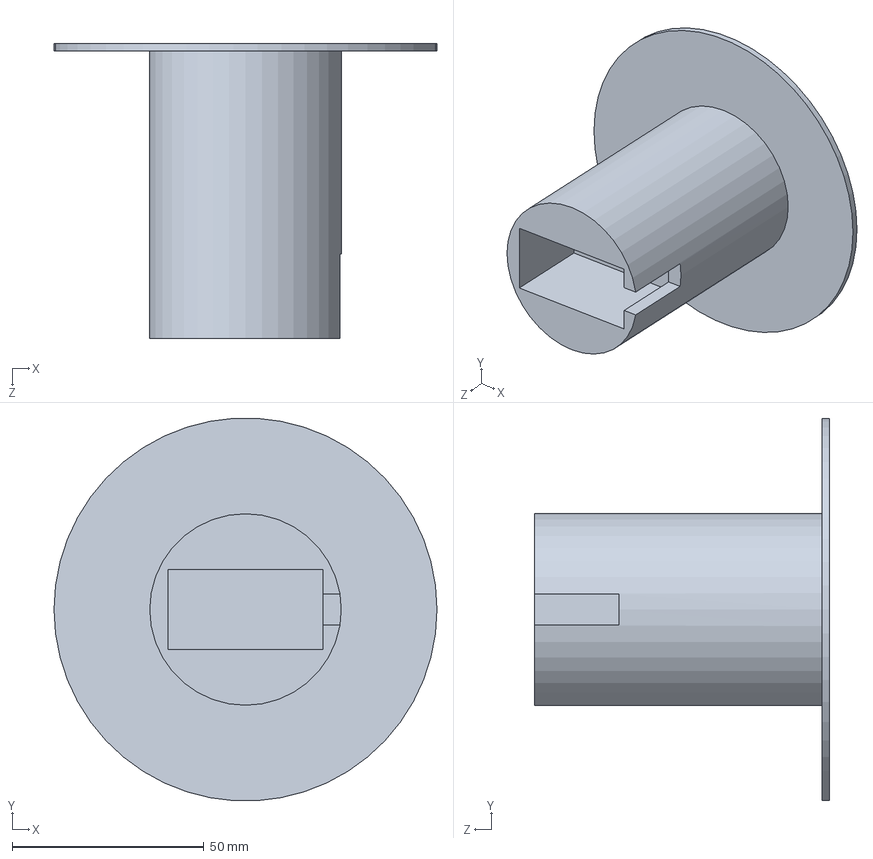
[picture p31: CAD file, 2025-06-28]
Auto_sampler/hardwares/servo shelf.SLDPRT
100.0 x 99.8 x 77.0 mm

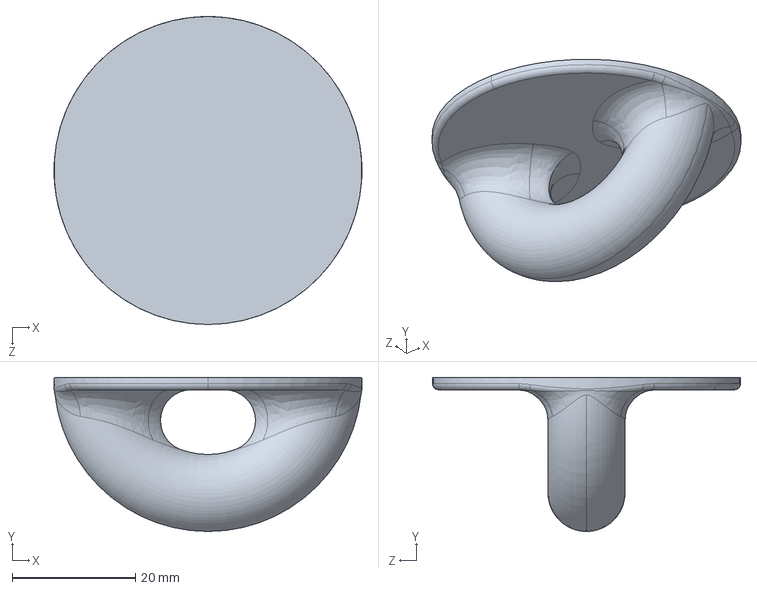
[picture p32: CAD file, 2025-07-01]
3D_Models/Anchor hook.STEP
50.0 x 25.0 x 50.0 mm

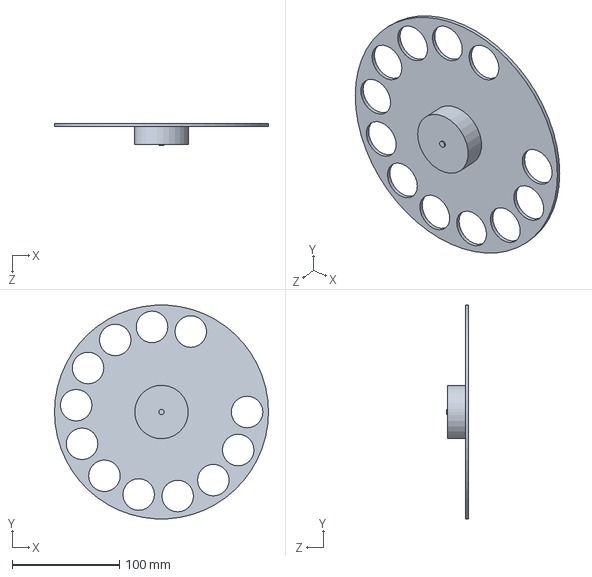
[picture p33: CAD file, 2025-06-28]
Auto_sampler/hardwares/sample plate.SLDPRT
200.0 x 199.7 x 21.0 mm

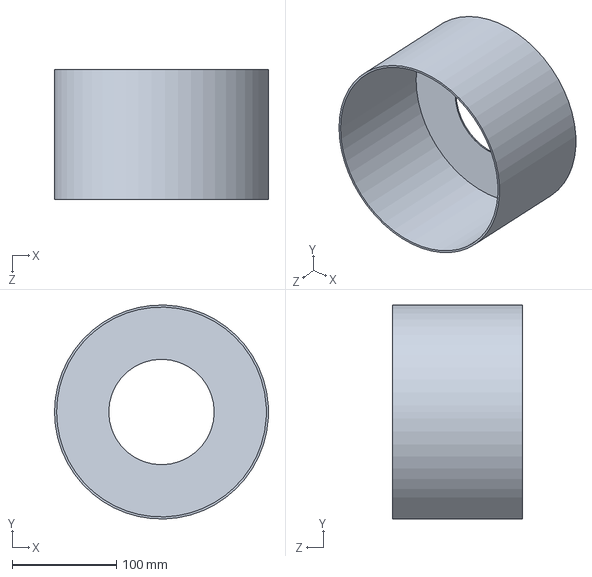
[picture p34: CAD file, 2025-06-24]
Auto_sampler/hardwares/sample cover.SLDPRT
205.0 x 204.9 x 125.0 mm

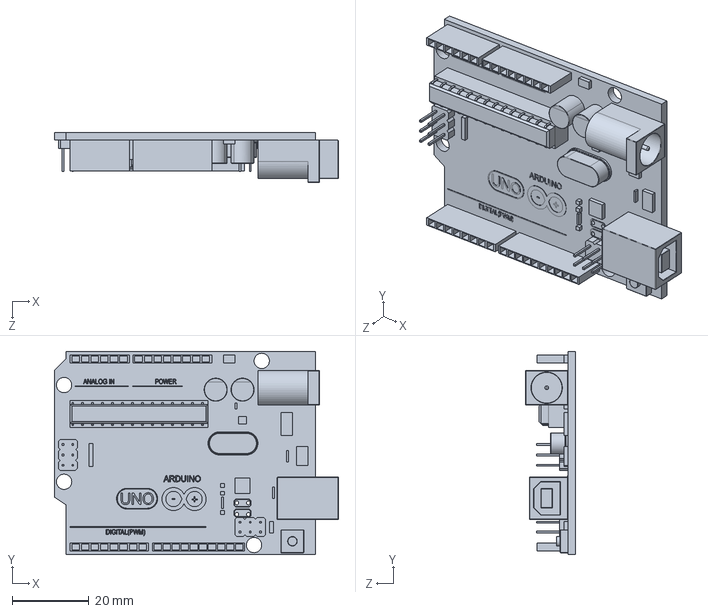
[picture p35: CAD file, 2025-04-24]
3D_Models/Arduino.SLDPRT
74.0 x 53.0 x 13.0 mm

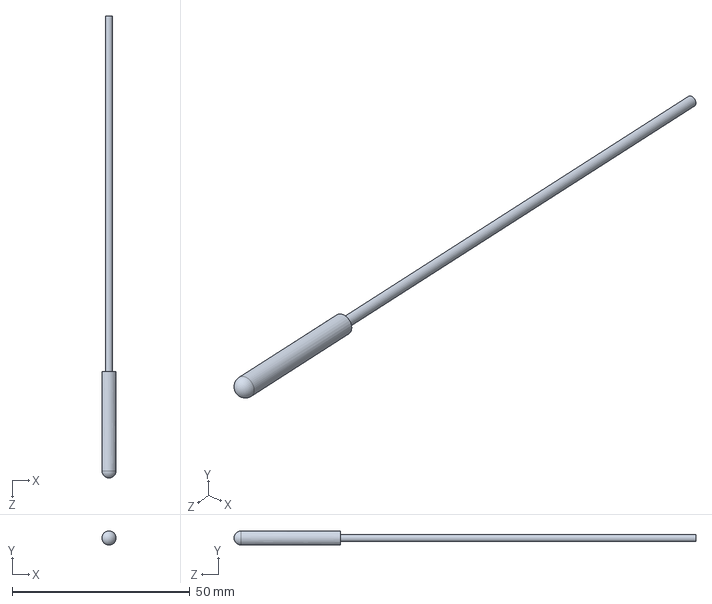
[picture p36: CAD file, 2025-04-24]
3D_Models/S Temperature Sensor.SLDPRT
4.00 x 4.00 x 130.0 mm

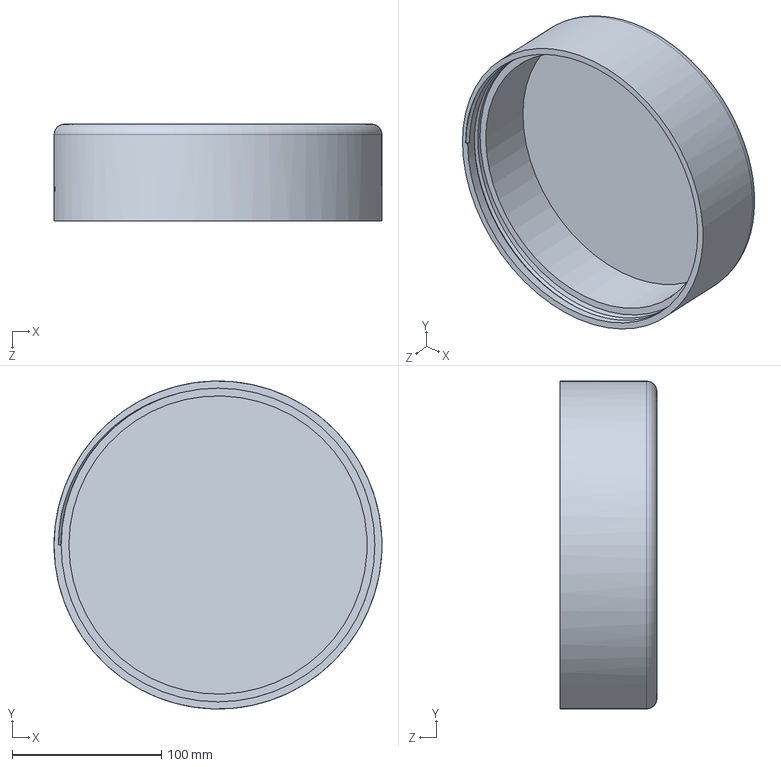
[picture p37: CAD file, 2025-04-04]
3D_Models/top Cover.SLDPRT
220.0 x 220.0 x 65.0 mm

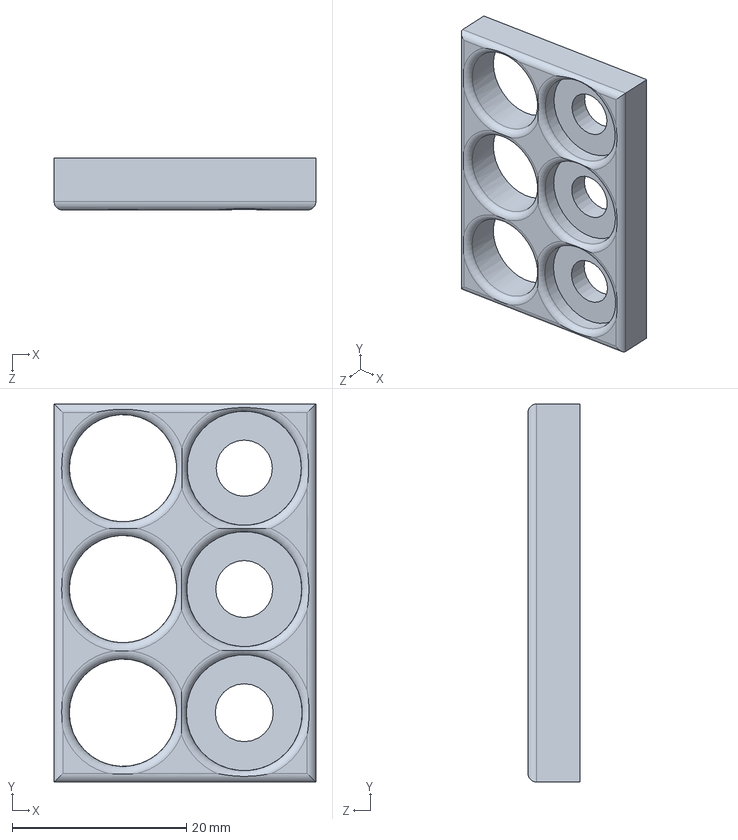
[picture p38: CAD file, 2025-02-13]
3D_Models/New Hole test.SLDPRT
30.1 x 43.4 x 6.00 mm

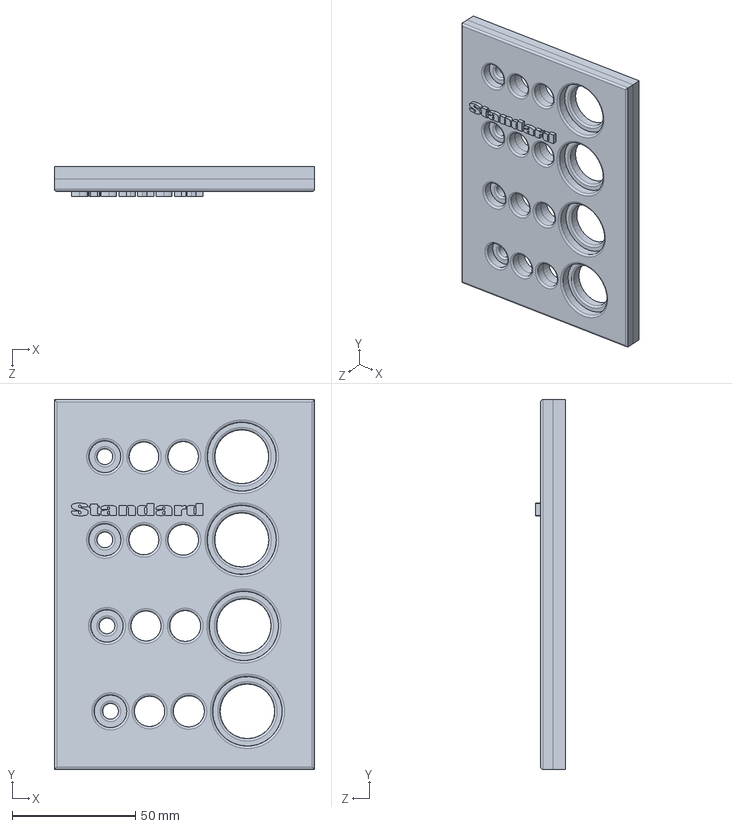
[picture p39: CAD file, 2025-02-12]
3D_Models/Hole test.SLDPRT
105.7 x 150.1 x 12.0 mm

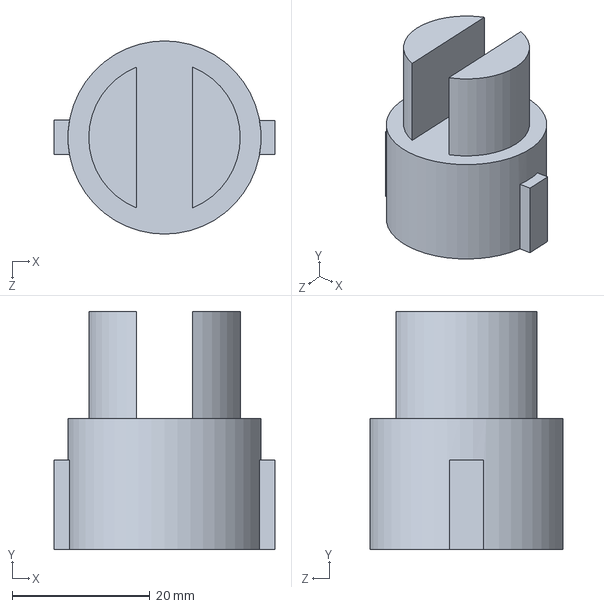
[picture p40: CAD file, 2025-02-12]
3D_Models/S Turdibity Sensor.SLDPRT
32.0 x 34.5 x 28.0 mm

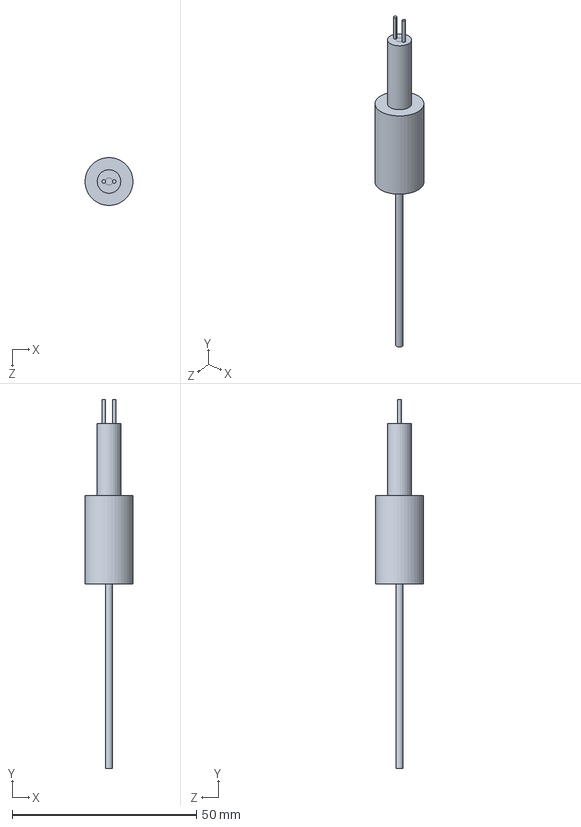
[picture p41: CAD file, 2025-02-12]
3D_Models/S Conductivity Sensor.SLDPRT
13.0 x 100.1 x 13.0 mm

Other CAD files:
3D_Models/Battery.SLDASM
3D_Models/matrix.SLDPRT
3D_Models/S Dissolved oxygen.SLDPRT
3D_Models/Anchor hook.SLDPRT
3D_Models/S PH Sensor.SLDPRT
3D_Models/out Cover Mid.SLDPRT
3D_Models/out Cover bottom.SLDPRT
Auto_sampler/hardwares/Motor holder.SLDPRT

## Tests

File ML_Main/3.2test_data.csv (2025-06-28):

sample.samplingPoint.notation | sample.samplingPoint.label | sample.sampleDateTime | Oxygen Diss | Temp Water | pH | ln Turd | ln Cond | ln Coliform | cos_day_of_year | sin_day_of_year | cos_time_of_day | sin_time_of_day | Oxygen Diss * Temp Water | Oxygen Diss * pH | Oxygen Diss * ln Turd | Oxygen Diss * ln Cond | Oxygen Diss * cos_day_of_year | Oxygen Diss * sin_day_of_year | Oxygen Diss * cos_time_of_day | Temp Water * pH | Temp Water * ln Turd | Temp Water * ln Cond | Temp Water * cos_day_of_year | Temp Water * sin_day_of_year | Temp Water * cos_time_of_day | pH * ln Turd | pH * ln Cond | pH * cos_day_of_year | pH * sin_day_of_year | pH * cos_time_of_day | ln Turd * ln Cond | ln Turd * cos_day_of_year | ln Turd * sin_day_of_year | ln Turd * cos_time_of_day | ln Cond * cos_day_of_year | ln Cond * sin_day_of_year | ln Cond * cos_time_of_day | cos_day_of_year * sin_day_of_year | cos_day_of_year * cos_time_of_day | sin_day_of_year * cos_time_of_day | Oxygen Diss n/(n+1) | Temp Water n/(n+1) | pH n/(n+1) | ln Turd n/(n+1) | ln Cond n/(n+1) | cos_day_of_year n/(n+1) | sin_day_of_year n/(n+1)
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

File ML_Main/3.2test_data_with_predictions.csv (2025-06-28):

sample.samplingPoint.notation | sample.samplingPoint.label | sample.sampleDateTime | Oxygen Diss | Temp Water | pH | ln Turd | ln Cond | ln Coliform | cos_day_of_year | sin_day_of_year | cos_time_of_day | sin_time_of_day | Oxygen Diss * Temp Water | Oxygen Diss * pH | Oxygen Diss * ln Turd | Oxygen Diss * ln Cond | Oxygen Diss * cos_day_of_year | Oxygen Diss * sin_day_of_year | Oxygen Diss * cos_time_of_day | Temp Water * pH | Temp Water * ln Turd | Temp Water * ln Cond | Temp Water * cos_day_of_year | Temp Water * sin_day_of_year | Temp Water * cos_time_of_day | pH * ln Turd | pH * ln Cond | pH * cos_day_of_year | pH * sin_day_of_year | pH * cos_time_of_day | ln Turd * ln Cond | ln Turd * cos_day_of_year | ln Turd * sin_day_of_year | ln Turd * cos_time_of_day | ln Cond * cos_day_of_year | ln Cond * sin_day_of_year | ln Cond * cos_time_of_day | cos_day_of_year * sin_day_of_year | cos_day_of_year * cos_time_of_day | sin_day_of_year * cos_time_of_day | Oxygen Diss n/(n+1) | Temp Water n/(n+1) | pH n/(n+1) | ln Turd n/(n+1) | ln Cond n/(n+1) | cos_day_of_year n/(n+1) | sin_day_of_year n/(n+1) | Prediction
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

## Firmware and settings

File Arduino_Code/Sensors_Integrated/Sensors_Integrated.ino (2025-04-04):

#include <avr/sleep.h>
#include <avr/interrupt.h>
#include <SoftwareSerial.h>
#include <Adafruit_MAX31865.h>

#define TDS_PIN A0
#define TUR_PIN A1
#define PH_PIN A2
#define DO_PIN A3
#define TEMP_PIN A4
#define MAX_CS 10  

#define LORA_RXD 0  // Connect the TXD to the LoRa module
#define LORA_TXD 1  // Connect the RXD to the LoRa module

#define VREF 5.0     
#define ADS_RES 1024.0
#define SCOUNT  5           // sum of sample point, array length
#define OFFSET 0.00            //deviation compensate
#define SAMPLE_INTERVAL 100U
#define PRINT_INTERVAL 500U

//single-point calibration
#define CAL1_V (1600) //unit mv
#define CAL1_T (25)   //unit ℃
// RTC The counter value ---- sleep time
#define RTC_PERIOD 1230 //normally 1250=10s

struct SensorData {
  int Array[SCOUNT];
  int bufferTemp[SCOUNT];
  float voltage;
  float value;
};
SensorData tdsData, turbidityData, pHData, doData;

volatile bool rtc_wakeup = false; // Used to signal whether the RTC is awake
volatile bool rtc_ifsleep = false; // Determine whether the device needs to sleep
int analogBufferIndex = 0,copyIndex = 0;
// !!! remove it when add temp sensor; this variable is also used in DO calculation
Adafruit_MAX31865 thermo = Adafruit_MAX31865(MAX_CS, 11, 12, 13);

// Create soft serial ports (to avoid communication serial port conflict)
SoftwareSerial loraSerial(LORA_RXD, LORA_TXD);

const int DO_Table[41] = {
  14460, 14220, 13820, 13440, 13090, 12740, 12420, 12110, 11810, 11530,
  11260, 11010, 10770, 10530, 10300, 10080, 9860, 9660, 9460, 9270,
  9080, 8900, 8730, 8570, 8410, 8250, 8110, 7960, 7820, 7690,
  7560, 7430, 7300, 7180, 7070, 6950, 6840, 6730, 6630, 6530, 6410
};


void readSensorData(SensorData *Do, SensorData *pH, SensorData *tur, SensorData *tds){
  // obtain temp from PT100 sensor
  temperature = thermo.temperature(100, 4300);

  // calculate DO values
  Do->voltage = getMedianNum(Do->bufferTemp, SCOUNT) * (float)VREF / ADS_RES;
  int V_saturation = CAL1_V + 35 * temperature - CAL1_T * 35;
  Do->value = Do->voltage * DO_Table[(int)temperature] / (V_saturation * 1000);

  // caluclate TDS values
  tds->voltage = getMedianNum(tds->bufferTemp, SCOUNT) * (float)VREF / ADS_RES;
  float compensationCoefficient = 1.0 + 0.02 * (temperature - 25.0);
  float compensationVolatge = tds->voltage / compensationCoefficient;
  float volSquare_tds = compensationVolatge * compensationVolatge;
  float volCube_tds = volSquare_tds * compensationVolatge;
  tds->value = (133.42f * volCube_tds - 255.86f * volSquare_tds + 857.39f * compensationVolatge) * 0.5f; 

  // calculate Turbidity values
  tur->voltage = getMedianNum(tur->bufferTemp, SCOUNT) * (float)VREF / ADS_RES;
  float volSquare_tur = tur->voltage * tur->voltage;
  tur->value = -1120.4 * volSquare_tur + 5742.3 * tur->voltage - 4352.9;

  // calculate pH values
  pH->voltage = getMedianNum(pH->bufferTemp, SCOUNT) * (float)VREF / ADS_RES;
  pH->value = 3.5 * pH->voltage + OFFSET;

  Serial.print("DO Value: ");
  Serial.println(Do->value, 2); 
  Serial.print("TDS Value: ");
  Serial.print(tds->value, 0);
  Serial.println(" ppm");
  /*
  Serial.print("Turbidity: ");
  Serial.print(tur->value, 0);
  Serial.println(" NTU");
  Serial.print("pH Value: ");
  Serial.println(pH->value, 2);
  Serial.print("Temperature: ");
  Serial.println(temperature, 2);*/

  loraSerial.print(Do->value); loraSerial.print(",");
  loraSerial.print(tds->value); loraSerial.print(",");
  loraSerial.print(tur->value); loraSerial.print(",");
  loraSerial.print(pH->value); loraSerial.print(",");
  loraSerial.println(temperature);
}

void sampleData(){
  //every 40ms, read the analog value from the ADC
  static unsigned long analogSampleTime = millis();
  // every 800ms, process the analog data
  static unsigned long printTime = millis();

  if (millis() - analogSampleTime > SAMPLE_INTERVAL) {
    analogSampleTime = millis();
    tdsData.Array[analogBufferIndex] = analogRead(TDS_PIN);
    turbidityData.Array[analogBufferIndex] = analogRead(TUR_PIN);
    pHData.Array[analogBufferIndex] = analogRead(PH_PIN);
    doData.Array[analogBufferIndex] = analogRead(DO_PIN);
    analogBufferIndex++;
    if (analogBufferIndex == SCOUNT) 
      analogBufferIndex = 0;
  }

  if (millis() - printTime > PRINT_INTERVAL) {
    printTime = millis();
    for (int i = 0; i < SCOUNT; i++) {
      tdsData.bufferTemp[i] = tdsData.Array[i];
      turbidityData.bufferTemp[i] = turbidityData.Array[i];
      pHData.bufferTemp[i] = pHData.Array[i];
      doData.bufferTemp[i] = doData.Array[i];
    }
    readSensorData(&doData, &pHData, &turbidityData, &tdsData);
    rtc_ifsleep = true;
  }
}

// medium filter, remove outliers
int getMedianNum(int bArray[], int iFilterLen) {
  int bTab[iFilterLen];
  memcpy(bTab, bArray, iFilterLen * sizeof(int));

  int i, j, bTemp;
  for (j = 0; j < iFilterLen - 1; j++) {
    for (i = 0; i < iFilterLen - j - 1; i++) {
      if (bTab[i] > bTab[i + 1]) {
        bTemp = bTab[i];
        bTab[i] = bTab[i + 1];
        bTab[i + 1] = bTemp;
      }
    }
  }

  if ((iFilterLen & 1) > 0)
    return bTemp = bTab[(iFilterLen - 1) / 2];
  else
    return bTemp = (bTab[iFilterLen / 2] + bTab[iFilterLen / 2 - 1]) / 2;
}

// Setup RTC timer
void setupRTC() {
  // 1. 使能 RTC，并选择 32kHz 内部振荡器作为时钟源
  while (RTC.STATUS > 0); 
  RTC.CLKSEL = RTC_CLKSEL_INT32K_gc; // 选择内部 32kHz 振荡器
  // 2. 设置 RTC 计数器周期
  RTC.PER = RTC_PERIOD;
  // 3. 使能 RTC 溢出中断
  RTC.INTCTRL = RTC_OVF_bm;
  // 4. 使能 RTC 并启动计数
  RTC.CTRLA = RTC_RTCEN_bm | RTC_PRESCALER_DIV256_gc | RTC_RUNSTDBY_bm; // 预分频 256（125Hz 计数）
  // 5. 开启全局中断
  sei();
}

void enterSleep() {
  Serial.println("Fall asleep...");
  Serial.flush();
  set_sleep_mode(SLEEP_MODE_STANDBY); // Enter Standby mode (RTC still running)
  sleep_enable();
  sleep_cpu();  // Enter the sleep mode and wait for the RTC to wake up

  sleep_disable();
}

ISR(RTC_CNT_vect) {
  RTC.INTFLAGS = RTC_OVF_bm; // Clear interrupt flags
  rtc_wakeup = true;
}

void setup(){
    Serial.begin(115200);
    while (!Serial);

    pinMode(TDS_PIN,INPUT);
    pinMode(TUR_PIN,INPUT);
    pinMode(PH_PIN,INPUT);
    pinMode(DO_PIN, INPUT);
    pinMode(TEMP_PIN, INPUT);
    Serial.println("Pins Initialized!");

    thermo.begin(MAX31865_3WIRE);

    loraSerial.begin(9600);
    Serial.println("LoRa Sender Initialized!");
    setupRTC();
    Serial.println("RTC Initialized!");
}

void loop(){
  if (rtc_ifsleep) {
    enterSleep();

    if (rtc_wakeup) {
      Serial.println("RTC wakes up the system");
      rtc_wakeup = false; // Reset flag
    }
    Serial.println("Wake up by RTC!");
    Serial.flush();
  }

  rtc_ifsleep = false;
  
  sampleData();
  delay(1000);
}

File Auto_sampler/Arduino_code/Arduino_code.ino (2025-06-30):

#include <Servo.h>
#include <avr/interrupt.h> 

#define In1 9
#define In2 8
#define In3 7
#define In4 6

#define RTC_PERIOD 1250 //normally 1250=10s

Servo myServo;  // 创建Servo对象


void setup() {
  myServo.attach(2);  
  
  pinMode(In1, OUTPUT);
  pinMode(In2, OUTPUT);
  pinMode(In3, OUTPUT);
  pinMode(In4, OUTPUT);

}

void loop() {
  
  static int angle = 0;  
  static bool done = false;

  if (done) {
    return;
  }

  myServo.write(angle);
  delay(1000);
  
  digitalWrite(In3, HIGH);
  digitalWrite(In4, LOW);
  delay(2000);
  digitalWrite(In3, LOW);
  digitalWrite(In4, LOW);

  digitalWrite(In1, LOW);
  digitalWrite(In2, HIGH);
  delay(1000);
  digitalWrite(In1, LOW);
  digitalWrite(In2, LOW);
  delay(2000);


  angle += 15;
  if (angle > 180) {
    done = true; 
  }
}

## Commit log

2025-01-19 Add Solidworks model
    [Arduino.prt, Assem.SLDASM, out Cover.SLDPRT]
2025-01-20 #0.0.1 Data correlation form open source data set
    [Indian_water_data_2014.csv, Water_pond_tanks_2021.csv]
2025-01-20 #0.0.2 Finish part SW model design.
    [Assem.SLDASM, S Conductivity Sensor.SLDPRT, S PH Sensor.SLDPRT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]
2025-01-21 #0.0.3 Add temperature Sensor and bread board.
    [Assem.SLDASM, S Temperature Sensor.SLDPRT, matrix.SLDPRT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]
2025-01-22 Filter dataset
    [Flitered_Indian_water_data_2014.csv, IOTMeterData_new.csv, Results_MADE.csv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]
2025-02-08 #0.0.7 Add Battery and Dissolved oxygen. Modify out cover.
    [Assem.SLDASM, Bateria.SLDASM, Dissolved oxygen.SLDPRT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]
2025-02-10 #0.0.9 Add .step for 3d print
    [out Cover.STEP]
2025-02-10 #0.0.10 New kind of out cover
    [Hole test.SLDPRT, Hole test.STEP, S Dissolved oxygen.SLDPRT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]
2025-02-12 #0.0.11 More accurate sensors size
    [S Conductivity Sensor.SLDPRT, S Dissolved oxygen.SLDPRT, S PH Sensor.SLDPRT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]
2025-02-12 #0.0.12 Add hole test board
    [Hole test.SLDPRT, Hole test.STEP]
2025-02-12 #0.0.13
    Add Arduino code
2025-02-13 #0.0.14 Add new hole tester
    [New Hole test.SLDPRT, New Hole test.STEP]
2025-02-15 #0.1.0
    First version of 3D model design finished
    [Separate Assem.SLDASM, out Cover Mid.SLDPRT]
2025-02-17 #0.1.1
    Modify Mid cover file
    [out Cover Mid.SLDPRT]
2025-02-26 #0.1.4
    Modify middle out cover model file
    [out Cover Mid.SLDPRT]
2025-02-26 #0.2.0 Merge Inconsistency results and save data over 5/6
    [2.5filtered_data.csv]
2025-03-04 #0.2.4 Newest useful data with full 5 params
    [2.6useful_data_New.csv]
2025-03-04 #0.2.5 Add time cos calculate
    [2.7cos_transformed.csv]
2025-03-04 #0.3.2 Add LoRa communication and RTC in Final code
    [sensor_data.csv]
2025-03-07 #0.3.4 Final available datas with time
    [2.7sin_cos_transformed.csv]
2025-03-07 #0.3.6 Delete wrong datas
    [2.7sin_cos_transformed.csv]
2025-03-11 #0.3.6 test part in this code seems like accurate
    [stations_encoded_data_PCA.csv]
2025-03-23 #0.4.0 First version of Hosing design
    [out Cover Mid.SLDPRT, out Cover Mid.STEP, out Cover bottom.SLDPRT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]
2025-03-24 #0.4.1 Better fits top cover
    [top Cover.SLDPRT, top Cover.STEP]
2025-04-04 #0.4.2 Update receive and send code
    [sensor_data.csv]
2025-04-24 #0.4.3 Update 3D model
    [Assem1.SLDASM, S Temperature Sensor.SLDPRT]
2025-04-24 #1.0.0 Presentation and showcase
    [Arduino.SLDPRT]
2025-06-23 Add sample and arduino model
    [sample plate.SLDPRT, sample plate.STEP]
2025-06-23 Add model
    [servo shelf.SLDPRT, servo shelf.STEP]
2025-06-23 Add more steps
    [2.5Flitered_New_3~5usefuldata.csv, 2.5Flitered_New_4~5.csv, 2.5Flitered_New_5.csv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]
2025-06-23 Find similar stations' data
    [negative_data.csv, test_data.csv]
2025-06-23 Rearrange folder name
    [2.5Flitered_New_3~5usefuldata.csv, 2.5Flitered_New_4~5.csv, 2.5Flitered_New_5.csv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]
2025-06-23 Add Auto sampler folder
2025-06-24 Add new
    [sample cover.SLDPRT, sample cover.STEP]
2025-06-28 #1.0.1 Modify Auto sampler 3d design
    [sample plate.SLDPRT, servo shelf.SLDPRT]
2025-06-28 #1.0.2 Move Tommy's code to try folder
    [Flitered_Indian_water_data_2014.csv, IOTMeterData_new.csv, Indian_water_data_2014.csv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]
2025-06-28 #1.1.0 Rearrange full and final content in ML folder
    [2.0extracted_columns_all_kinds.csv, 2.9sin_cos_with_new_features.csv, 3.2test_data.csv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]
2025-06-28 #1.1.2 Move hardware model to sampler folder
    [sample cover.SLDPRT, sample plate.SLDPRT, servo shelf.SLDPRT]
2025-06-28 #1.1.3 Rearrangement
    [Arduino.prt, Assem.SLDASM, Assem1.SLDASM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]
2025-06-28 #1.1.5 Add multi cross compare baselines.
    Tandom Forest, XGBoost, MLP-2L, Linear Regression, Turbility-only
    [A.a baseline_cross_results.csv]
2025-06-28 Remove a #NUM
    [2.6useful_data_New.csv]
2025-06-30 #1.2.1 Add arduino code of sampler
2025-06-30 #1.2.2 Remove old ML code.
    [Flitered_Indian_water_data_2014.csv, IOTMeterData_new.csv, Indian_water_data_2014.csv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]
2025-06-30 #1.2.3 Add BOM doc
    [BOM.xlsx]
2025-07-01 #1.2.4 Add Motor holder for Sampler
    [Motor holder.SLDPRT, Motor holder.STEP]
2025-07-01 #1.2.5 Add anchor hook
    [Anchor hook.SLDPRT, Anchor hook.STEP]
2025-07-01 #1.2.7 Remove useless one-station-code
    [4.1one_station.csv, 5.2all_feature_importances.csv, 5.3same_feature_data.csv]
2025-07-02 #1.2.8 update BOM
    [BOM.xlsx]
2025-07-14 #1.2.9 Add SETP file for 3d printing
    [out Cover Mid.STEP, out Cover bottom.STEP]
2025-07-14 #1.2.10 New Motor holder design.
    [Motor holder.SLDPRT, Motor holder.STEP]
